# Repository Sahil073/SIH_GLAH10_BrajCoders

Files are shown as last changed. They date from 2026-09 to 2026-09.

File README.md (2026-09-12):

# Sanjeevni: Offline Wearable Telemetry & Edge AI Companion







Sanjeevni is an offline-first wearable telemetry system and on-device health safety companion. Designed for industrial workers, underground miners, high-altitude workers, and remote patients, it continuously captures physiological and environmental vitals via a multi-sensor ESP32 wearable and streams them over Bluetooth Low Energy (BLE) to an Android smartphone.

All biomedical signal processing, Pan-Tompkins QRS detection, motion classification, heat-stress modeling, and risk scoring execute locally on the mobile device CPU. No internet connection, cellular data, or external cloud infrastructure is required.

---

## System Architecture & Data Pipeline

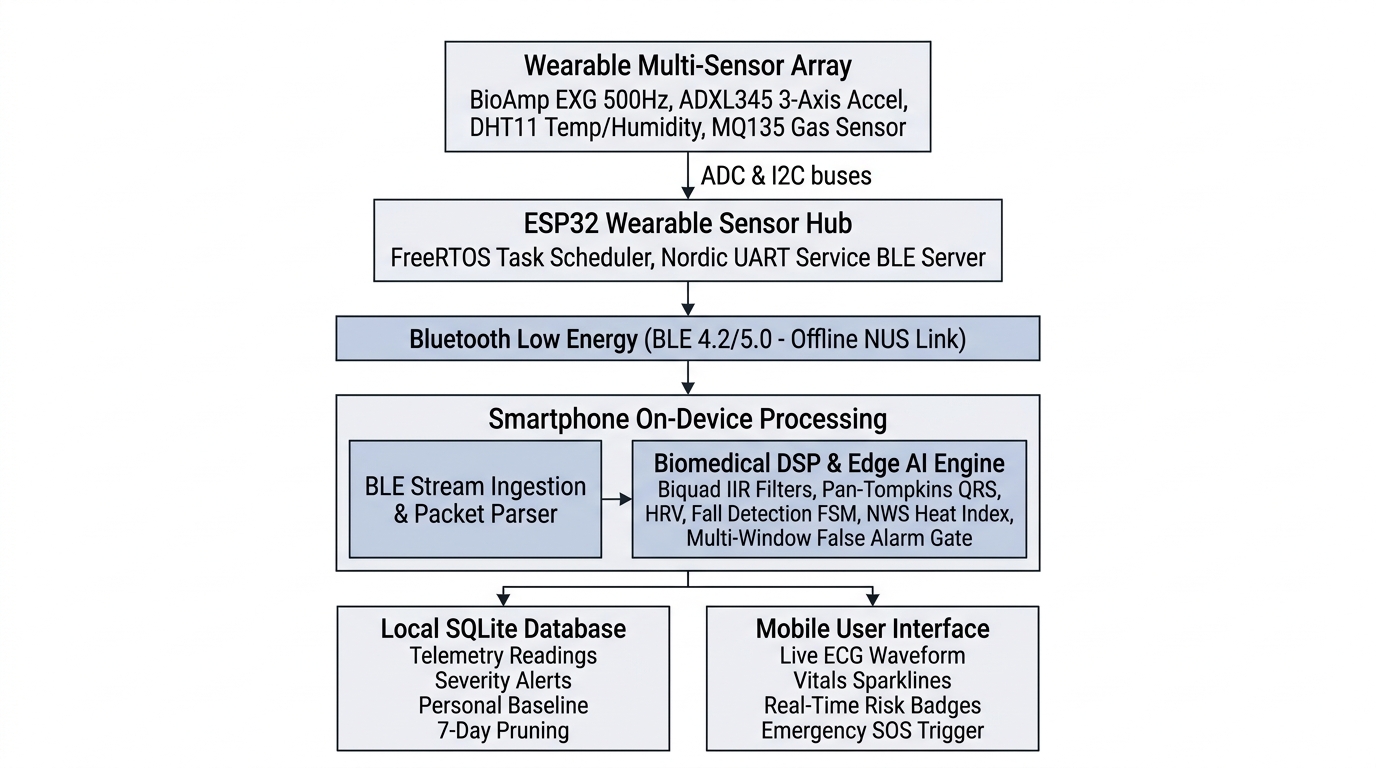
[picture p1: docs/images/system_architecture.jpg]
Sanjeevni System Architecture


---

## Repository Structure

```text
SIH_GLAH10_BrajCoders/
├── Hardware/                          # Firmware, testing sketches, PCB and hardware docs
│   ├── Device-Testing/                # 2-Tier component verification suite
│   │   ├── ADXL345/                   # Standalone I2C accelerometer serial test
│   │   ├── ADXL_Bluetooth/            # BLE stream test for ADXL345 (25 Hz)
│   │   ├── Bioamp_EXG/                # Standalone biopotential ADC serial test
│   │   ├── Bioamp_EXG_Bluetooth/      # BLE stream test for BioAmp EXG (500 Hz, 128-sample)
│   │   ├── Bluetooth/                 # BLE NUS loopback echo test
│   │   ├── DHT11/                     # Standalone digital temperature/humidity test
│   │   ├── DHT_Bluetooth/             # BLE stream test for DHT11 (0.5 Hz)
│   │   ├── LED/                       # GPIO and ESP32 clock sanity check
│   │   ├── MQ135/                     # Standalone hazardous gas ADC serial test
│   │   ├── MQ135_Bluetooth/           # BLE stream test for MQ135 (1 Hz)
│   │   ├── Moisture/                  # Standalone moisture ADC serial test
│   │   ├── Moisture_Bluetooth/        # BLE stream test for moisture sensor (0.5 Hz)
│   │   └── DEVICE_TESTING_GUIDE.md    # Modular hardware verification instructions
│   ├── ESP32_Sensor_Hub/              # Production multi-sensor BLE firmware
│   │   └── ESP32_Sensor_Hub.ino       # Full FreeRTOS multi-rate scheduler
│   ├── Sanjeevni_PCB/                 # Custom KiCad PCB files & manufacturing guide
│   │   ├── Sanjeevni_PCB.kicad_sch    # Schematic design
│   │   ├── Sanjeevni_PCB.kicad_pcb    # 2-layer PCB layout
│   │   ├── PCB schema.pdf             # Exported schematic reference
│   │   ├── PCB design.pdf             # Exported board layout reference
│   │   ├── PCB_Schematic.pdf          # Exported schematic reference
│   │   ├── PCB_Design.pdf             # Exported board layout reference
│   │   ├── PCB_Design_Guide.md        # Comprehensive electrical BOM and layout notes
│   │   ├── README.md                  # PCB subsystem overview and stackup
│   │   └── images/                    # 3D board renders
│   ├── HARDWARE_DOCS.md               # Pinouts, electrical specifications and BLE format
│   ├── README.md                      # Hardware overview and getting started guide
│   └── sample_data.txt                # 1,130 lines of verified field telemetry
│
├── docs/                              # Project specifications and hackathon decks
│   ├── images/                        # Research-style architecture and system diagrams
│   ├── BrajCoder's_SIH_Round1.pdf     # Smart India Hackathon Round 1 presentation
│   ├── BrajCoders_SIH_Round1.pdf      # Smart India Hackathon Round 1 presentation
│   ├── BrajCoders_SIH_2026.pdf        # SIH project submission & architectural slides
│   ├── sanjeevni_app_spec.pdf         # Mobile application technical specification
│   ├── sanjeevni_buildguide.pdf       # Hardware assembly and prototyping guide
│   └── DOCS_GUIDE.md                  # Index and overview of project documents
│
├── mobile-app/                        # React Native + Expo mobile application
│   ├── ai-engine/                     # On-device biomedical DSP and decision pipeline
│   │   ├── baseline/                  # Welford's online running baseline engine
│   │   ├── buffers/                   # High-performance RingBuffer
│   │   ├── decision/                  # Multi-window false-alarm gate & risk rules
│   │   ├── ecg/                       # Biquad IIR filters, Pan-Tompkins, HR & HRV
│   │   ├── environment/               # NWS Rothfusz heat index & AQI classifier
│   │   ├── fusion/                    # Multi-modal cross-sensor risk fusion
│   │   ├── mock/                      # Synthetic telemetry generator for simulator mode
│   │   ├── motion/                    # Dynamic activity state & 3-stage fall FSM
│   │   ├── __tests__/                 # Automated 7-test AI pipeline test suite
│   │   ├── index.ts                   # processSensorTick() main entrypoint
│   │   ├── types.ts                   # Strict data contracts for all sensor inputs
│   │   └── README.md                  # Comprehensive mathematical specification
│   ├── databaseConnections/           # On-device SQLite persistence layer
│   │   ├── database.ts                # Schema v4 table definitions, CRUD & pruning
│   │   ├── database.web.ts            # Web-safe mock fallback for browsers
│   │   ├── __tests__/                 # Automated 12-test database test suite
│   │   └── README.md                  # Table schemas, indices & retention policy
│   ├── src/                           # Mobile frontend source code
│   │   ├── app/                       # Expo Router tab layouts and navigation screens
│   │   │   ├── (auth)/                # Sign-in and sign-up flows (Clerk auth)
│   │   │   ├── (tabs)/                # Dashboard, Alerts, History, SOS, Profile
│   │   │   ├── _layout.tsx            # App initialization, providers & DB/AI bridge
│   │   │   └── connect-device.tsx     # BLE device discovery and pairing screen
│   │   ├── ble/                       # BLE Central manager, reassembly & reactive store
│   │   ├── components/                # Reusable UI widgets, sparklines, modals
│   │   ├── database/                  # On-device SQLite persistence layer (Schema v4)
│   │   │   ├── index.ts               # Public API wrapper & multi-user queries
│   │   │   ├── database.ts            # Schema definitions, CRUD & retention pruning
│   │   │   ├── database.web.ts        # Web-safe mock fallback for browsers
│   │   │   ├── vitalsHistory.ts       # Time-series vitals history query service
│   │   │   ├── __tests__/             # Automated 12-test database test suite
│   │   │   └── README.md              # Table schemas, indices & retention policy
│   │   ├── hooks/                     # Custom hooks (useDashboardData, useBle, useAiRisk)
│   │   └── services/                  # aiBridge.ts (BLE -> AI Pipeline -> SQLite)
│   ├── __tests__/                     # End-to-end hardware-to-UI integration test
│   ├── app.json                       # Expo configuration, Android permissions & plugins
│   ├── eas.json                       # Standalone APK build profile (arm64-v8a)
│   ├── package.json                   # Mobile dependencies and npm scripts
│   └── README.md                      # Mobile subsystem documentation
│
├── package.json                       # Root developer convenience test scripts
└── README.md                          # Project documentation and run guide
```

---

## Hardware Setup & Firmware Flashing

### 1. Prerequisites

- **Arduino IDE**: Version 2.x ([Download Arduino IDE](https://www.arduino.cc/en/software))
- **ESP32 Board Package**: Install `esp32` by Espressif via `Boards Manager`
- **Required Libraries** (via `Tools > Manage Libraries...`):
  - `Adafruit ADXL345`
  - `Adafruit Unified Sensor`
  - `DHT sensor library` (by Adafruit)
  - `ArduinoJson` (by Benoit Blanchon, v6.x or v7.x)

### 2. Sensor Pinout Mapping

| Sensor Module | Physical Interface | ESP32 GPIO | Operating Voltage | Notes |
| :--- | :--- | :--- | :--- | :--- |
| **BioAmp EXG Pill** | Analog Voltage | `GPIO 34` | 3.3V | ADC1_CH6 (Input-only, 500 Hz sampling) |
| **ADXL345** | I2C | `GPIO 21` (SDA)<br>`GPIO 22` (SCL) | 3.3V | I2C Address `0x53` (SDO to GND) |
| **DHT11** | Proprietary 1-Wire | `GPIO 4` | 3.3V / 5V | Digital I/O (10 kΩ pull-up required if bare) |
| **MQ135** | Analog Voltage | `GPIO 35` | 5.0V (Heater)<br>3.3V (ADC) | ADC1_CH7 (Input-only, heater requires 5V) |
| **Moisture Sensor** | Analog Voltage | `GPIO 32` | 3.3V | ADC1_CH4 (Supports digital and analog) |

> **Critical ADC Note:** Only ADC1 pins are used. ADC2 pins (`GPIO 0, 2, 4, 12, 13, 14, 15, 25, 26, 27`) cannot be used for analog reads when Bluetooth or Wi-Fi is active.

### 3. Flashing the Sensor Hub Firmware

1. Connect your ESP32 Dev Module via micro-USB.
2. In Arduino IDE, select:
   - **Board**: `ESP32 Dev Module`
   - **Upload Speed**: `921600`
   - **Flash Frequency**: `80MHz`
   - **Port**: Select your active COM port.
3. Open [`Hardware/ESP32_Sensor_Hub/ESP32_Sensor_Hub.ino`](Hardware/ESP32_Sensor_Hub/ESP32_Sensor_Hub.ino).
4. Click **Upload**.
5. Once uploaded, open the Serial Monitor at `115200 baud`. The ESP32 will initialize all sensors and start advertising over BLE as **`ESP32_SENSOR_HUB_BLE`**.

---

## Mobile App Setup & Execution

### 1. Prerequisites

- **Node.js**: v18.x or v20.x LTS ([Download Node.js](https://nodejs.org))
- **npm**: v9.x or higher
- **Physical Android Phone**: Bluetooth 4.2+ and Location enabled (for native BLE testing).

### 2. Installation & Configuration

```bash
# 1. Navigate to the mobile app directory
cd mobile-app

# 2. Copy the sample environment file
cp .env.example .env

# 3. Install dependencies
npm install --legacy-peer-deps
```

### 3. Running in Development

#### Option A: Expo Go (Simulation Mode)

```bash
npm start
```

- Scan the displayed QR code with the **Expo Go** application on Android.
- Because native BLE binary drivers are unavailable inside Expo Go, Sanjeevni automatically engages its built-in mathematical synthetic generator (`syntheticDataGenerator.ts`). It generates realistic 500 Hz ECG waveforms, accelerometer tilts, and ambient thermal cycles for full UI testing.

#### Option B: Standalone Android APK (Physical BLE Mode)

To connect to the physical ESP32 hardware, compile an installable standalone `.apk`:

```bash
# Via EAS Cloud Build:
npm install -g eas-cli
npx eas login
npx eas build -p android --profile preview

# Or compile locally with Gradle:
npx expo prebuild --platform android
cd android
./gradlew assembleRelease -PreactNativeArchitectures=arm64-v8a
```

Install the resulting `.apk` on your phone, enable Bluetooth, power on the ESP32, and launch Sanjeevni. The app will pair and start streaming telemetry without internet or Wi-Fi.

---

## Automated Verification & Test Suites

The project includes unit and integration tests across the entire stack. Run them from the workspace root:

### Run All Test Suites:

```bash
npm test
```

### Run Individual Test Suites:

1. **On-Device AI Engine Test Suite** (`7/7 Passed`):

   ```bash
   npm run test:ai
   ```

   - Test 1: Biquad IIR Bandpass (0.5–40 Hz) & 50 Hz Notch filter attenuation.
   - Test 2: Pan-Tompkins QRS peak detection and RR interval validation.
   - Test 3: Mathematical derivation of BPM, RMSSD, and SDNN.
   - Test 4: Dynamic motion classification and 3-stage fall detection FSM.
   - Test 5: Environmental Heat Index calculation against NOAA benchmark tables.
   - Test 6: Full end-to-end `processSensorTick()` pipeline orchestration.
   - Test 7: Multi-window emergency alarm and false-alarm gate trigger logic.

2. **SQLite Database & Schema Test Suite** (`12/12 Passed`):

   ```bash
   npm run test:db
   ```

   - Test 1: Schema creation, tables (`readings`, `alerts`, `user_profile`, `rolling_baseline`), and indices.
   - Test 2: Readings insertion and query operations.
   - Test 3: Alerts table insertion and severity enum check constraint (`LOW`, `MODERATE`, `HIGH`, `CRITICAL`).
   - Test 4: Single-profile configuration constraint.
   - Test 5: Rolling baseline upsert via `ON CONFLICT DO UPDATE`.
   - Test 6: Automated 7-day circular data pruning.
   - Test 7: Sensor aggregate statistics calculations.
   - Test 8: Historical sensor queries with timestamp ordering and pagination limits.
   - Test 9: Alert deletion and bulk clear operations.
   - Test 10: Rich user profile persistence and local session management.
   - Test 11: Multi-user data isolation and tenant partitioning.
   - Test 12: 6-month historical data rollup downsampling and user erasure utility.

3. **End-to-End System Integration Test**:

   ```bash
   npm run test:e2e
   ```

   - Step 1: Parses raw multi-chunk ESP32 Nordic UART BLE packets.
   - Step 2: Executes the sliding-window AI pipeline.
   - Step 3: Verifies persistent storage in the local SQLite database.

4. **TypeScript Type Checking**:
   ```bash
   npm run typecheck
   ```

   - Validates TypeScript types across the entire mobile codebase (0 errors).

---

## BLE Protocol Reference (Nordic UART Service)

The ESP32 communicates using the Nordic UART Service (NUS):

| Identifier | UUID Value |
| :--- | :--- |
| **Service UUID** | `6E400001-B5A3-F393-E0A9-E50E24DCCA9E` |
| **RX Characteristic (Write)**  | `6E400002-B5A3-F393-E0A9-E50E24DCCA9E` |
| **TX Characteristic (Notify)** | `6E400003-B5A3-F393-E0A9-E50E24DCCA9E` |

### Telemetry Packet Payloads (Newline Delimited `\n`)

- **BioAmp EXG (Sensor ID 1)**:
  `{"v":1,"sensor":1,"seq":104,"rate":500,"samples":[2048,2060,2090,...],"ts":181482}\n`
- **ADXL345 (Sensor ID 2)**:
  `{"v":1,"sensor":2,"seq":4518,"data":{"x":0.15,"y":-0.22,"z":9.81},"ts":181483}\n`
- **DHT11 (Sensor ID 3)**:
  `{"v":1,"sensor":3,"seq":120,"data":{"temperature":32.5,"humidity":68.0},"ts":181500}\n`
- **MQ135 (Sensor ID 4)**:
  `{"v":1,"sensor":4,"seq":180,"data":{"raw":480},"ts":181751}\n`
- **Moisture Sensor (Sensor ID 5)**:
  `{"v":1,"sensor":5,"seq":95,"data":{"raw":520},"ts":181800}\n`

---

## Offline Privacy & Data Integrity

- **Zero Cloud Transmission**: All ECG analysis, Pan-Tompkins QRS detection, and environmental evaluations execute on the smartphone CPU. No biometric data leaves the device.
- **Local SQLite Retention**: Telemetry and safety alerts are stored in an encrypted/sandboxed local SQLite database (`sanjeevni.db`) with an automated 7-day circular pruning policy to preserve phone storage.
- **Credential Protection**: Environment files and keys are excluded via `.gitignore`.

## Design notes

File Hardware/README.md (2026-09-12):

# Hardware Subsystem — ESP32 Sensor Hub

This directory contains the firmware, modular hardware testing suite, KiCad custom PCB designs, and hardware documentation for the Sanjeevni wearable device.

---

## Directory Structure

```text
Hardware/
├── ESP32_Sensor_Hub/              # Production multi-sensor BLE GATT firmware
│   └── ESP32_Sensor_Hub.ino       # Non-blocking multi-rate scheduler and NUS streamer
├── Device-Testing/                # Modular 2-tier testing sketches & verification guide
│   ├── ADXL345/                   # Standalone I2C accelerometer diagnostic
│   ├── ADXL_Bluetooth/            # Component-level BLE test for ADXL345 (25 Hz)
│   ├── Bioamp_EXG/                # Standalone biopotential ADC diagnostic (Serial Plotter)
│   ├── Bioamp_EXG_Bluetooth/      # Component-level BLE test for BioAmp EXG (500 Hz, 128-sample chunks)
│   ├── Bluetooth/                 # BLE NUS bidirectional loopback and throughput test
│   ├── DHT11/                     # Standalone digital temperature and humidity diagnostic
│   ├── DHT_Bluetooth/             # Component-level BLE test for DHT11 (0.5 Hz)
│   ├── LED/                       # GPIO driver and ESP32 clock sanity check
│   ├── MQ135/                     # Standalone hazardous gas ADC diagnostic
│   ├── MQ135_Bluetooth/           # Component-level BLE test for MQ135 (1 Hz)
│   ├── Moisture/                  # Standalone skin/soil moisture ADC diagnostic
│   ├── Moisture_Bluetooth/        # Component-level BLE test for moisture sensor (0.5 Hz)
│   └── DEVICE_TESTING_GUIDE.md    # Complete test procedure and output reference
├── Sanjeevni_PCB/                 # Custom hardware PCB design files
│   ├── Sanjeevni_PCB.kicad_sch    # KiCad schematic
│   ├── Sanjeevni_PCB.kicad_pcb    # KiCad 2-layer PCB layout
│   ├── PCB schema.pdf             # Exported schematic PDF
│   ├── PCB design.pdf             # Exported board layout PDF
│   ├── PCB_Schematic.pdf          # Exported schematic PDF
│   ├── PCB_Design.pdf             # Exported board layout PDF
│   ├── PCB_Design_Guide.md        # Circuit theory, BOM, and assembly guide
│   ├── README.md                  # PCB folder overview and layer stackup
│   └── images/                    # 3D renders (top view, isometric views)
├── HARDWARE_DOCS.md               # Detailed hardware specification and electrical reference
└── sample_data.txt                # 1,130 lines of live captured telemetry from field testing
```

---

## Sensor Interface & Pin Allocations

These pin allocations are strictly adhered to by the production firmware [`ESP32_Sensor_Hub.ino`](ESP32_Sensor_Hub/ESP32_Sensor_Hub.ino) and all Tier 2 BLE testing sketches:

| Sensor Module | Physical Interface | ESP32 GPIO | Channel / Type | Sampling Rate | BLE Transmission Rate |
| :--- | :--- | :--- | :--- | :--- | :--- |
| **BioAmp EXG Pill** | Analog Voltage Out | `GPIO 34` | ADC1_CH6 (Input-only) | 500 Hz (2 ms period via `micros()`) | ~3.9 Hz (128 samples / packet) |
| **ADXL345** | I2C (Address `0x53`) | `GPIO 21` (SDA)<br>`GPIO 22` (SCL) | Hardware I2C | 100 Hz (10 ms period) | 25 Hz (40 ms period) |
| **DHT11** | Proprietary 1-Wire | `GPIO 4` | Digital I/O | 0.5 Hz (2000 ms period) | 0.5 Hz |
| **MQ135** | Analog Voltage Out | `GPIO 35` | ADC1_CH7 (Input-only) | 10 Hz (100 ms period) | 1 Hz (10-sample rolling average) |
| **Moisture Sensor** | Analog Voltage Out | `GPIO 32` | ADC1_CH4 (ADC + Digital) | 10 Hz (100 ms period) | 0.5 Hz (10-sample rolling average) |

> **ADC Note:** All analog sensors use ADC1 pins (`GPIO 32`, `34`, `35`). In ESP32 microcontrollers, ADC2 cannot be used simultaneously with active Wi-Fi or Bluetooth Low Energy due to internal RF hardware multiplexing.

---

## Bluetooth Low Energy Protocol (NUS)

The ESP32 firmware operates as a BLE GATT Server running the **Nordic UART Service (NUS)**:

- **Advertised Peripheral Name:** `ESP32_SENSOR_HUB_BLE`
- **Primary Service UUID:** `6E400001-B5A3-F393-E0A9-E50E24DCCA9E`
- **TX Characteristic (Notify):** `6E400003-B5A3-F393-E0A9-E50E24DCCA9E` (Descriptor: `0x2902`)
- **RX Characteristic (Write):** `6E400002-B5A3-F393-E0A9-E50E24DCCA9E`
- **Negotiated MTU:** 517 bytes (`BLEDevice::setMTU(517)`)
- **Chunking:** Payloads are split into max 128-byte notifications with 2 ms yields to prevent notify buffer congestion.
- **Framing:** Compact JSON terminated by `\n` (newline).

### Packet Format Overview

Every packet includes version `"v": 1`, a numeric `"sensor"` ID (1–5), an independent per-sensor sequence number `"seq"`, and uptime `"ts"` in milliseconds:

```json
// Sensor 1: BioAmp EXG (500 Hz batch)
{"v":1,"sensor":1,"seq":104,"ts":181482,"rate":500,"samples":[2048,2060,2090,2085,...]}

// Sensor 2: ADXL345 Accelerometer (m/s²)
{"v":1,"sensor":2,"seq":4518,"ts":181483,"data":{"x":0.15,"y":-0.22,"z":9.81}}

// Sensor 3: DHT11 Temperature & Humidity
{"v":1,"sensor":3,"seq":120,"ts":181500,"data":{"temperature":32.5,"humidity":68.0}}

// Sensor 4: MQ135 Air Quality (raw 12-bit ADC)
{"v":1,"sensor":4,"seq":180,"ts":181751,"data":{"raw":480}}

// Sensor 5: Moisture (raw 12-bit ADC)
{"v":1,"sensor":5,"seq":95,"ts":181800,"data":{"raw":520}}
```

---

## Flashing Instructions

### Required Environment
- **Arduino IDE**: Version 2.0 or higher
- **Board Package**: `esp32` by Espressif Systems (v2.0.x or v3.0.x)
- **Board Selection**: `Tools > Board > esp32 > ESP32 Dev Module`
- **Upload Settings**:
  - Upload Speed: `921600`
  - CPU Frequency: `240MHz`
  - Flash Frequency: `80MHz`
  - Flash Mode: `QIO`
  - Partition Scheme: `Default 4MB with spiffs (1.2MB APP/1.5MB SPIFFS)`

### Required Arduino Libraries
Install these via the Arduino Library Manager (`Ctrl+Shift+I` / `Cmd+Shift+I`):
1. `Adafruit ADXL345` (Unified accelerometer driver)
2. `Adafruit Unified Sensor` (Base sensor abstraction)
3. `DHT sensor library` by Adafruit
4. `ArduinoJson` by Benoit Blanchon (version 6.x or 7.x)

The BLE stack (`BLEDevice`, `BLEServer`, `BLEUtils`, `BLE2902`) and `Wire` are included in the ESP32 core.

---

## Verification Workflow

1. **Standalone Validation**:
   Follow [`Device-Testing/DEVICE_TESTING_GUIDE.md`](Device-Testing/DEVICE_TESTING_GUIDE.md) to flash the standalone sketches (`ADXL345.ino`, `Bioamp_EXG.ino`, `DHT11.ino`, `MQ135.ino`, `Moisture.ino`) and view live physical metrics on the Serial Plotter (115200 baud).
2. **BLE Validation**:
   Flash the corresponding `*_Bluetooth.ino` sketches to verify BLE GATT discovery, characteristic subscriptions, and packet throughput.
3. **Full Integration**:
   Flash [`ESP32_Sensor_Hub/ESP32_Sensor_Hub.ino`](ESP32_Sensor_Hub/ESP32_Sensor_Hub.ino). Verify serial output confirms all sensors initialized, then connect using the Sanjeevni mobile application.
4. **Captured Telemetry**:
   Review [`sample_data.txt`](sample_data.txt) for real-world serial logs and payload samples recorded during field testing.

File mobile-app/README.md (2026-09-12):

# Sanjeevni Mobile Application

The Sanjeevni mobile application is an offline-first wearable telemetry and on-device health companion built with React Native and Expo (SDK 57). It connects to the ESP32 Wearable Sensor Hub over Bluetooth Low Energy (BLE) using the Nordic UART Service (NUS) to perform continuous biopotential signal processing, environmental safety analysis, motion tracking, and automated emergency alerting without requiring internet, cellular data, or cloud servers.

---

## Architecture Overview

The mobile application is structured into four decoupled layers:

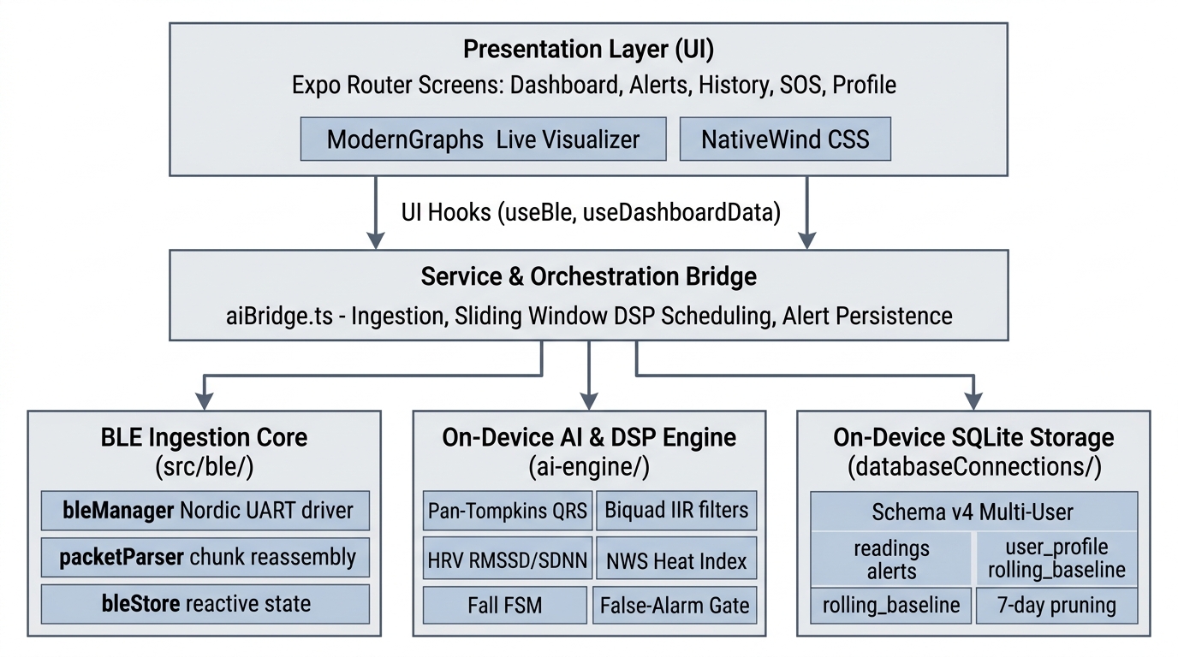
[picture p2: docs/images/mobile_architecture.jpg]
Sanjeevni Mobile Architecture


---

## Directory Structure

```text
mobile-app/
├── ai-engine/                          # Zero-dependency biomedical DSP & risk engine
│   ├── baseline/                       # Welford's running baseline & cold-start logic
│   ├── buffers/                        # Ring buffer for sliding-window calculations
│   ├── decision/                       # False-alarm hysteresis & risk decision engine
│   ├── ecg/                            # Biquad IIR filters, Pan-Tompkins, HR & HRV
│   ├── environment/                    # NWS Rothfusz heat index & AQI classifier
│   ├── fusion/                         # Multi-modal cross-sensor risk fusion
│   ├── mock/                           # Synthetic wave generator for simulator mode
│   ├── motion/                         # Activity state & fall detection state machine
│   ├── __tests__/                      # 7-test AI pipeline verification suite
│   ├── index.ts                        # processSensorTick() orchestrator
│   ├── package.json                    # Isolated package definition
│   └── README.md                       # In-depth DSP mathematical specification
├── databaseConnections/                # Local SQLite persistence engine
│   ├── database.ts                     # Schema v4 table definitions, CRUD & pruning
│   ├── database.web.ts                 # Safe in-memory mock fallback for web
│   ├── __tests__/                      # 12-test SQLite schema verification suite
│   └── README.md                       # Table schemas, indices & retention policy
├── src/                                # Mobile application source code
│   ├── app/                            # Expo Router file-based navigation
│   │   ├── (auth)/                     # Sign-in and sign-up views (Clerk auth)
│   │   ├── (tabs)/                     # Main bottom-tab views:
│   │   │   ├── index.tsx               # Dashboard (Live ECG, vitals sparklines, status)
│   │   │   ├── alerts.tsx              # Safety alerts log with acknowledgment
│   │   │   ├── history.tsx             # Historical telemetry trends & export
│   │   │   ├── sos.tsx                 # Emergency SOS trigger & contact calling
│   │   │   └── profile.tsx             # Medical profile, blood group & baselines
│   │   ├── _layout.tsx                 # Root layout, theme provider, DB initialization
│   │   ├── connect-device.tsx          # BLE device discovery & pairing modal
│   │   ├── onboarding.tsx              # First-launch feature walkthrough
│   │   └── onboarding-health.tsx       # Initial medical baseline setup
│   ├── ble/                            # Self-contained Bluetooth Low Energy module
│   │   ├── bleManager.ts               # Nordic UART Service GATT driver & auto-reconnect
│   │   ├── packetParser.ts             # Stream reassembly buffer & Base64/JSON parser
│   │   ├── bleStore.ts                 # Reactive telemetry store
│   │   ├── types.ts                    # Sensor contracts (Sensors 1-5)
│   │   ├── hooks/useBleConnection.ts   # Presentational hook for UI connection screens
│   │   └── README.md                   # BLE integration documentation
│   ├── components/                     # Modular UI components (charts, cards, banners)
│   ├── constants/                      # Image registries and theme constants
│   ├── data/                           # Mock datasets and metric details
│   ├── database/                       # Local SQLite persistence engine
│   │   ├── index.ts                    # Public API wrapper & safe multi-user queries
│   │   ├── database.ts                 # Schema v4 table definitions, CRUD & pruning
│   │   ├── database.web.ts             # Safe in-memory mock fallback for web
│   │   ├── vitalsHistory.ts            # Time-series vitals history aggregation service
│   │   ├── __tests__/                  # 12-test SQLite schema verification suite
│   │   └── README.md                   # Table schemas, indices & retention policy
│   ├── hooks/                          # Custom React hooks (useDashboardData, etc.)
│   ├── services/                       # aiBridge.ts (BLE -> AI Engine -> SQLite)
│   ├── store/                          # User profile and UI state stores
│   └── types/                          # Shared UI and dashboard types
├── __tests__/                          # Full end-to-end integration test
├── assets/                             # Fonts (Poppins) and app icons
├── plugins/                            # Custom Expo config plugins (ABI optimizations)
├── app.json                            # Expo manifest, Android permissions & plugins
├── eas.json                            # EAS build configuration (arm64-v8a target)
├── package.json                        # Mobile dependencies and npm scripts
├── tailwind.config.js                  # NativeWind Tailwind configuration
└── tsconfig.json                       # TypeScript compiler configuration with @/* aliases
```

---

## Execution Modes

The app supports two execution modes depending on runtime environment:

### 1. Expo Go (Simulation Mode)
- **Use Case**: Fast UI and application state development without needing a physical ESP32.
- **Behavior**: Because native C++/JNI Bluetooth drivers (`react-native-ble-plx`) cannot run inside the pre-compiled Expo Go client, the application automatically engages `syntheticDataGenerator.ts`.
- **Telemetry**: Generates mathematically realistic ECG waveforms (P-Q-R-S-T complexes at 500 Hz), dynamic 3-axis accelerometer tilts, and fluctuating ambient temperature/humidity cycles.

### 2. Standalone APK / Development Build (Hardware Mode)
- **Use Case**: Testing with the physical ESP32 Wearable Sensor Hub.
- **Behavior**: Initializes the full native Android BLE Central stack, requests necessary runtime permissions (`BLUETOOTH_SCAN`, `BLUETOOTH_CONNECT`, `ACCESS_FINE_LOCATION`), discovers `ESP32_SENSOR_HUB_BLE`, negotiates MTU 517, and ingests live sensor packets.

---

## Getting Started

### Prerequisites
- **Node.js**: v18.x or v20.x LTS
- **npm**: v9.x or higher
- **Expo CLI**: bundled via `npx expo`

### 1. Installation
Navigate to the `mobile-app` directory and install dependencies:
```bash
cd mobile-app
npm install --legacy-peer-deps
```

### 2. Environment Configuration
Copy the sample environment file:
```bash
cp .env.example .env
```
Edit `.env` if you need to configure authentication keys (a default offline bypass key is pre-filled).

### 3. Run in Development
Start the Expo bundler:
```bash
npm start
```
- Press **`a`** to open in an Android emulator.
- Scan the terminal QR code with **Expo Go** on an Android phone to run in Simulation Mode.

---

## Compiling Standalone Android APK

Because physical BLE communication requires native Android binaries, compile a standalone `.apk` for hardware testing:

### Option A: Cloud Build via EAS (Recommended)
```bash
# 1. Install EAS CLI
npm install -g eas-cli

# 2. Login to Expo
npx eas login

# 3. Build standalone preview APK
npx eas build -p android --profile preview
```

> **Build Optimization:** `eas.json` and `plugins/withReactNativeArchitectures.js` are configured to compile exclusively for `arm64-v8a`. This avoids building redundant 32-bit and emulator ABIs, reducing cloud compile times to ~6–8 minutes.

### Option B: Local Android Build
```bash
# 1. Generate native android project
npx expo prebuild --platform android

# 2. Compile release APK with Gradle
cd android
./gradlew assembleRelease -PreactNativeArchitectures=arm64-v8a
```
Output APK is located at: `android/app/build/outputs/apk/release/app-release.apk`.

---

## Testing & Verification

All test suites can be executed directly:

```bash
# 1. AI Biomedical DSP Test (7 tests):
npx tsx ai-engine/__tests__/aiPipeline.test.ts

# 2. SQLite Database & Schema Test (12 tests):
npx tsx databaseConnections/__tests__/databaseSchema.test.ts
npx tsx src/database/__tests__/databaseSchema.test.ts

# 3. Full End-to-End System Integration Test:
npx tsx __tests__/endToEndIntegration.test.ts

# 4. TypeScript Typecheck:
npm run typecheck
```

Or execute all tests in sequence:
```bash
npm test
```

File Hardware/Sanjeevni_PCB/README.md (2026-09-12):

# Sanjeevni Custom Wearable PCB

This directory contains the schematic design, printed circuit board (PCB) layout, 3D renderings, and manufacturing guidelines for the Sanjeevni wearable hardware prototype, designed using KiCad.

---

## Directory Contents

| File / Folder | Type | Description |
| :--- | :--- | :--- |
| [`Sanjeevni_PCB.kicad_sch`](Sanjeevni_PCB.kicad_sch) | KiCad Schematic | Full schematic capture including power regulation, ESP32 core, sensor front-ends, and programming pads. |
| [`Sanjeevni_PCB.kicad_pcb`](Sanjeevni_PCB.kicad_pcb) | KiCad Board Layout | 2-layer PCB layout routing power planes, high-frequency digital lines, and shielded analog tracks. |
| [`Sanjeevni_PCB.kicad_pro`](Sanjeevni_PCB.kicad_pro) | Project File | KiCad project configuration and library mappings. |
| [`PCB schema.pdf`](<PCB schema.pdf>) | Schematic Export | High-resolution PDF export of the complete circuit schematic for easy review without KiCad installed. |
| [`PCB design.pdf`](<PCB design.pdf>) | Layout Export | High-resolution PDF export of the top and bottom copper layers, silkscreen, and drill guides. |
| [`PCB_Schematic.pdf`](PCB_Schematic.pdf) | Schematic Export | High-resolution PDF export of the complete circuit schematic for easy review without KiCad installed. |
| [`PCB_Design.pdf`](PCB_Design.pdf) | Layout Export | High-resolution PDF export of the top and bottom copper layers, silkscreen, and drill guides. |
| [`PCB_Design_Guide.md`](PCB_Design_Guide.md) | Engineering Guide | In-depth documentation detailing the Bill of Materials (BOM), trace width calculations, noise isolation, and step-by-step routing methodology. |
| [`images/`](images/) | 3D Visualizations | Rendered views of the populated board: [top view](images/top%20view.png), [isometric view 1](images/isometric%20view.png), [isometric view 2](images/isometric%20view%202.png). |
| [`images/`](images/) | 3D Visualizations | Rendered views of the populated board: [top view](images/top_view.png), [isometric view 1](images/isometric_view_1.png), [isometric view 2](images/isometric_view_2.png). |

---

## Hardware Architecture & Design Decisions

### 1. Form Factor & Enclosure Considerations
- **Field-Sealed Wearable**: To ensure durability in harsh industrial or remote environments, the production board does not include an onboard micro-USB or Type-C port. 
- **Factory Programming Interface**: 6 exposed test pads (`GND`, `3V3`, `TX`, `RX`, `EN`, `IO0`) are positioned along the board edge, allowing firmware programming via a removable pogo-pin jig before sealing.
- **Power Connection**: 2-pin JST-PH 2.00 mm horizontal receptacle for standard 3.7V single-cell LiPo rechargeable batteries.

### 2. Sensor Integration Strategy
- **BioAmp EXG Pill (Daughterboard)**: Mounted via standard 2.54 mm female pin headers rather than integrating bare IC components. This isolates the sensitive biopotential instrumentation amplifier (110 dB CMRR, 4th-order active bandpass filter) from digital switching noise and RF ground bounce.
- **ADXL345 (Bare IC)**: Direct LGA-14 surface mount footprint on the I2C bus (`GPIO 21` SDA, `GPIO 22` SCL) with 4.7 kΩ pull-up resistors and local 100 nF decoupling.
- **DHT11 (Through-Hole Footprint)**: 4-pin single-row connector with pull-up resistor on the single-wire data line (`GPIO 4`).
- **MQ135 (Raw Element)**: 6-pin circular footprint for the bare electrochemical gas sensing element. Driven by an onboard MT3608 boost converter providing the required 5V rail for the internal heating element.

### 3. Power Distribution Architecture
- **Battery Input**: 3.7V nominal LiPo (operating range 3.0V – 4.2V).
- **3.3V Logic Rail**: AMS1117-3.3 low-dropout linear regulator providing clean 3.3V power to the ESP32-WROOM-32D module, ADXL345, DHT11, and BioAmp EXG Pill. Bulk decoupling capacitors (10 µF tantalum + 100 nF ceramic) are placed directly at the regulator and MCU pins.
- **5.0V Heater Rail**: MT3608 DC-DC step-up switching regulator stepping 3.7V up to 5.0V dedicated exclusively to the MQ135 heating coil. Thermal relief vias and a dedicated ground return keep switching noise out of the analog measurement circuits.

---

## Fabrication Specifications

- **Layer Count**: 2 Layers (Top Layer: Signal & Power, Bottom Layer: Unbroken Ground Plane)
- **Board Material**: Standard FR-4
- **Finished Copper Weight**: 1 oz (35 µm)
- **Dielectric Thickness**: 1.6 mm
- **Minimum Trace Width**: 0.25 mm (10 mil) for signal traces; 0.6 mm (24 mil) for 3.3V power distribution
- **Minimum Clearance**: 0.2 mm (8 mil)
- **Minimum Drill Hole Size**: 0.3 mm (via), 0.9 mm (through-hole component pins)

For the complete component catalog, KiCad symbol mappings, and step-by-step routing layout instructions, consult [`PCB_Design_Guide.md`](PCB_Design_Guide.md).

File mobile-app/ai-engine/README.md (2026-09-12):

# On-Device AI & Biomedical DSP Engine

This directory contains the core digital signal processing (DSP), statistical feature extraction, sensor fusion, and risk decision engine for Sanjeevni. It is designed as an isolated, zero-dependency TypeScript module that executes entirely on the mobile CPU (100% offline).

---

## Architectural Principles

1. **Deterministic DSP & Statistical Rules (Phase 1)**:
   Avoids heavyweight black-box neural networks in favour of validated biomedical algorithms (Pan-Tompkins QRS detection, Biquad IIR filtering, Welford's online variance, NWS Rothfusz polynomial). This guarantees real-time execution (<5 ms per tick) with minimal battery consumption and predictable failure modes.
2. **Zero Framework Coupling**:
   No dependencies on React Native, Expo, or native OS binaries. The engine can be tested directly in Node.js or run inside a Web Worker, headless service, or mobile JavaScript runtime.
3. **Strict Per-User State Isolation**:
   Filter memories, ring buffers, and baseline tracking are maintained in per-user instances (`runtimeByUser = Map<string, RuntimeState>()`) to eliminate cross-session data contamination.
4. **Physiologically Conservative**:
   Missing or noise-corrupted sensor inputs remain explicitly `null` rather than falling back to default "healthy" constants.

---

## Subsystem Breakdown

```text
ai-engine/
├── baseline/                  # Welford's running baseline & cold-start calibration
│   └── personalBaseline.ts
├── buffers/                   # High-performance sliding-window buffers
│   └── ringBuffer.ts          # O(1) circular ring buffer implementation
├── decision/                  # Alarm confirmation & recommendation generation
│   ├── falseAlarmGate.ts      # Multi-window persistence & motion masking
│   └── riskDecisionEngine.ts  # Final risk stratification and SOS trigger logic
├── ecg/                       # Biomedical signal processing pipeline
│   ├── filters.ts             # Biquad IIR 0.5–40 Hz bandpass + 50 Hz notch filter
│   ├── sqi.ts                 # Motion-aware Signal Quality Index (kurtosis, SNR)
│   ├── rPeakDetection.ts      # Pan-Tompkins adaptive dual-threshold peak detector
│   ├── rrValidation.ts        # 300–2000 ms physiological interval validation
│   ├── heartRate.ts           # Rolling heart rate (BPM) calculation
│   ├── hrv.ts                 # Time-domain HRV extraction (RMSSD, SDNN)
│   └── rhythmAnomaly.ts       # Bradycardia, tachycardia & arrhythmia detection
├── environment/               # Microclimate & environmental hazard modeling
│   ├── aqiSource.ts           # MQ135 ADC mapping to EPA AQI bands
│   ├── heatIndex.ts           # NWS Rothfusz equation & Steadman regression
│   └── respiratoryRisk.ts     # Combined thermal-gas pulmonary hazard scoring
├── fusion/                    # Multi-modal risk aggregation
│   └── sensorFusion.ts        # Weighted cross-domain risk synthesis
├── mock/                      # Hardware simulation for Expo Go
│   └── syntheticDataGenerator.ts # Generates realistic P-Q-R-S-T waves & tilt
├── __tests__/                 # Automated test suite
│   └── aiPipeline.test.ts     # 7-stage pipeline verification
├── types.ts                   # Strict data contracts for all inputs & outputs
├── index.ts                   # Public orchestrator: processSensorTick()
└── package.json               # Standalone package definition
```

---

## Algorithm Details

### 1. ECG Signal Conditioning (`ecg/filters.ts`)
Raw 500 Hz analog samples from the BioAmp EXG Pill undergo a 2-stage digital filtering cascade:
- **0.5–40 Hz Bandpass Filter**: Second-order IIR Biquad filters suppress baseline wander caused by respiration (<0.5 Hz) and electromyographic muscle noise (>40 Hz).
- **50 Hz Notch Filter**: Second-order IIR Notch filter ($Q = 30$) eliminates AC mains hum from nearby electrical wiring.

### 2. Pan-Tompkins QRS Detection (`ecg/rPeakDetection.ts`)
The filtered biopotential stream is evaluated via a classical Pan-Tompkins implementation:
1. **Derivative Operator**: Emphasizes the steep slope of the QRS complex ($y[n] = (2x[n] + x[n-1] - x[n-3] - 2x[n-4]) / 8$).
2. **Squaring Function**: Non-linearly amplifies the high-frequency QRS energy and forces all values positive.
3. **Moving Window Integrator**: Integrates energy over a 150 ms window ($\approx 75$ samples at 500 Hz).
4. **Adaptive Dual Thresholding**: Automatically adapts signal and noise peak thresholds based on running averages:
   $$\text{Threshold} = \text{NoiseLevel} + 0.25 \times (\text{SignalLevel} - \text{NoiseLevel})$$
5. **Refractory Blanking**: Enforces a 200 ms minimum lockout period between adjacent peaks to prevent double-counting T-waves.

### 3. Signal Quality Index (`ecg/sqi.ts`)
Before computing heart metrics, each batch of ECG samples is evaluated against three quality criteria:
- **Saturation / Lead-Off Check**: Flags ADC values locked at rails (`4095` or `0`).
- **Kurtosis & Relative Energy**: Computes 4th-order statistical moment to ensure peakiness characteristic of genuine QRS complexes.
- **Motion Gating**: Reads simultaneous dynamic acceleration from the ADXL345; if motion exceeds threshold, classifies as `MOTION_CORRUPTED` to prevent false arrhythmia triggers.

### 4. Heart Rate & HRV Calculation (`ecg/heartRate.ts`, `ecg/hrv.ts`)
- **RR Interval Validation**: Discards intervals outside 300 ms (200 BPM) to 2000 ms (30 BPM) or exhibiting unphysiological step jumps (>30% variance from previous interval).
- **Heart Rate**: Derived from the median of validated RR intervals over the observation window:
  $$\text{HR} = \frac{60000}{\text{median}(RR_i)} \text{ BPM}$$
- **RMSSD**: Root mean square of successive RR interval differences, reflecting parasympathetic autonomic activity:
  $$\text{RMSSD} = \sqrt{\frac{1}{N-1} \sum_{i=1}^{N-1} (RR_{i+1} - RR_i)^2}$$
- **SDNN**: Standard deviation of all normal-to-normal intervals over the observation window.

### 5. Fall Detection Finite State Machine (`motion/fallDetection.ts`)
Evaluates 3-axis accelerometer vectors $|\vec{a}| = \sqrt{x^2 + y^2 + z^2}$:
1. **Stage 1 (Freefall)**: Total vector drops below $0.5\text{g}$ for $\ge 60\text{ ms}$.
2. **Stage 2 (Impact)**: Vector experiences an abrupt acceleration spike exceeding $2.5\text{g}$ within $500\text{ ms}$ of freefall.
3. **Stage 3 (Post-Impact Immobility)**: Evaluates subsequent motion for $2.0\text{ s}$. If acceleration variance remains $<0.15\text{g}$, flags a `CONFIRMED` fall event.

### 6. Environmental Thermal Index (`environment/heatIndex.ts`)
Uses the comprehensive National Weather Service (NWS) Rothfusz regression equation for temperatures above $26.7^\circ\text{C}$ ($80^\circ\text{F}$) and relative humidity between 0% and 100%:
$$\text{HI} = c_1 + c_2 T + c_3 RH + c_4 T \cdot RH + c_5 T^2 + c_6 RH^2 + c_7 T^2 RH + c_8 T \cdot RH^2 + c_9 T^2 RH^2$$
Applies adjustment factors for low humidity / high temperature and high humidity / moderate temperature regimes.

### 7. False-Alarm Gate & Multi-Sensor Fusion (`decision/falseAlarmGate.ts`, `fusion/sensorFusion.ts`)
- **Persistence Verification**: Isolated anomalous ticks do not trigger high-severity alerts. An event must persist across consecutive evaluation windows.
- **Cross-Domain Correlation**: High heart rate during intense physical activity (high motion RMS) is classified as physiological exertion rather than panic or ventricular tachycardia. Conversely, high heart rate combined with zero motion and elevated ambient heat index increases the heat exhaustion risk score.
- **Emergency SOS Decision**: Recommends triggering the SOS workflow if confirmed fall occurs with sustained immobility, or if severe multi-risk convergence is detected.

---

## Testing

The AI engine includes an automated end-to-end verification script testing all DSP stages:

```bash
# Run from workspace root:
npm run test:ai

# Or run directly:
npx tsx mobile-app/ai-engine/__tests__/aiPipeline.test.ts
```

### Verified Test Cases:
1. **ECG Filter Chain**: Attenuation of 50 Hz noise and DC baseline drift.
2. **Pan-Tompkins Detection**: QRS peak detection and RR interval validation on simulated waveforms.
3. **HR & HRV Computation**: Correct mathematical derivation of BPM, RMSSD, and SDNN.
4. **Motion Classification & Fall Engine**: Rest vs vigorous activity, and 3-stage fall confirmation.
5. **NWS Heat Index**: Validated against NOAA benchmark tables for multiple $(T, RH)$ pairs.
6. **Full Pipeline Orchestration**: Validates `processSensorTick()` output structure and bounds.
7. **SOS Alarm Gating**: Multi-window confirmation under emergency stress conditions.

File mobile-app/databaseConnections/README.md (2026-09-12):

# Database Subsystem — On-Device SQLite Storage

This directory implements the local, zero-cloud SQLite persistence layer for the Sanjeevni mobile application using `expo-sqlite`. It stores real-time physiological vitals, security alerts, emergency contact configurations, and personal baseline statistics directly on the mobile device.

---

## Directory Layout

```text
databaseConnections/
├── database.ts                      # Core SQLite engine, Schema v4 migrations, CRUD & pruning
├── database.web.ts                  # Web-safe mock fallback for browser execution
├── __tests__/
│   └── databaseSchema.test.ts       # 12-test automated verification suite
└── README.md                        # This specification
```

---

## Database Architecture (Schema v4)

Database file name: `sanjeevni.db`

### Tables & Indices

#### 1. `readings`
Stores continuous, downsampled vital telemetry and sensor metrics streamed from the ESP32.

```sql
CREATE TABLE IF NOT EXISTS readings (
  id INTEGER PRIMARY KEY AUTOINCREMENT,
  user_id TEXT NOT NULL DEFAULT 'offline_local',
  timestamp TEXT NOT NULL,
  sensor_type TEXT NOT NULL,
  value REAL NOT NULL,
  source TEXT NOT NULL,
  synced INTEGER DEFAULT 0
);

CREATE INDEX IF NOT EXISTS idx_readings_sensor_timestamp 
  ON readings(sensor_type, timestamp);
CREATE INDEX IF NOT EXISTS idx_readings_user_sensor_ts 
  ON readings(user_id, sensor_type, timestamp);
```

- `sensor_type`: Standardized identifiers (`HEART_RATE`, `ECG_SQI`, `HRV_RMSSD`, `TEMPERATURE`, `HUMIDITY`, `HEAT_INDEX`, `AQI_RAW`, `SKIN_MOISTURE`, `MOTION_MAGNITUDE`, `STEP_COUNT`).
- `source`: Origin marker (`hardware_ble`, `ai_engine`, or `simulation`).
- `synced`: 0 = local only, 1 = synced (reserved for future optional manual exports).

#### 2. `alerts`
Stores critical physiological thresholds, fall events, and environmental hazard triggers.

```sql
CREATE TABLE IF NOT EXISTS alerts (
  id INTEGER PRIMARY KEY AUTOINCREMENT,
  user_id TEXT NOT NULL DEFAULT 'offline_local',
  timestamp TEXT NOT NULL,
  category TEXT NOT NULL,
  severity TEXT CHECK(severity IN ('LOW', 'MODERATE', 'HIGH', 'CRITICAL')) NOT NULL,
  message TEXT NOT NULL,
  acknowledged INTEGER DEFAULT 0
);

CREATE INDEX IF NOT EXISTS idx_alerts_timestamp ON alerts(timestamp);
CREATE INDEX IF NOT EXISTS idx_alerts_user_ts ON alerts(user_id, timestamp);
```

#### 3. `user_profile`
Persists the active user's demographic parameters, emergency contact details, and baseline vulnerability flags.

```sql
CREATE TABLE IF NOT EXISTS user_profile (
  user_id TEXT PRIMARY KEY,
  name TEXT DEFAULT 'Sanjeevni User',
  email TEXT DEFAULT 'user@sanjeevni.health',
  pin TEXT DEFAULT '',
  age INTEGER DEFAULT 25,
  gender TEXT DEFAULT 'Other',
  height_cm REAL DEFAULT 170,
  weight_kg REAL DEFAULT 65,
  blood_group TEXT DEFAULT 'O+',
  medical_condition TEXT DEFAULT 'None',
  emergency_name TEXT DEFAULT 'Emergency Contact',
  emergency_phone TEXT DEFAULT '+91 98765 43210',
  is_logged_in INTEGER DEFAULT 1,
  baseline_values TEXT,
  vulnerability_flags TEXT,
  emergency_contact TEXT
);
```

#### 4. `rolling_baseline`
Maintains running statistical aggregates (Welford's online mean and variance) for individual user baseline calibration.

```sql
CREATE TABLE IF NOT EXISTS rolling_baseline (
  user_id TEXT NOT NULL,
  metric TEXT NOT NULL,
  mean REAL NOT NULL,
  variance REAL NOT NULL,
  count INTEGER NOT NULL,
  last_updated TEXT NOT NULL,
  PRIMARY KEY (user_id, metric)
);
```

---

## Data Lifecycle & Retention

To prevent unbounded flash memory growth on wearable mobile hosts:

1. **7-Day Rolling Pruning (`pruneOldReadings`)**:
   Deletes raw high-frequency `readings` older than 7 days based on ISO-8601 timestamps:
   ```sql
   DELETE FROM readings WHERE timestamp < datetime('now', '-7 days');
   ```
2. **6-Month Rollup Downsampling (`rollupHistoricalData`)**:
   Rolls up historical data into hourly averages before purging long-term raw records.
3. **Multi-User Isolation (`normalizeUserId`)**:
   Every query filters strictly by `user_id`. When unauthenticated or in offline guest mode, defaults to `'offline_local'`.

---

## Testing & Verification

The database layer includes 12 automated unit tests covering table creation, bounded enum constraints, index efficiency, CRUD operations, multi-user partitioning, and retention pruning:

```bash
# Run from workspace root:
npm run test:db

# Or run directly inside mobile-app:
npx tsx databaseConnections/__tests__/databaseSchema.test.ts
```

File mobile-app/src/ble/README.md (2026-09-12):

# Sanjeevni BLE / Hardware Communication Module

> **Sub-repo integration guide for [SIH_GLAH10_BrajCoders](https://github.com/Sahil073/SIH_GLAH10_BrajCoders)**  
> This module encapsulates the complete Bluetooth Low Energy (BLE 4.2 / 5.0) communication pipeline between the ESP32 Sensor Hub and the Sanjeevni React Native mobile app.

---

## Architecture & File Layout

```text
src/ble/
├── index.ts                 # Public barrel export for the entire BLE module
├── types.ts                 # Authoritative contracts for Sensors 1–5 & BLE state
├── packetParser.ts          # Stream reassembly buffer, Base64 decoding, JSON/CSV parser
├── bleManager.ts            # Nordic UART Service (NUS) driver, auto-reconnect, simulation
├── bleStore.ts              # Reactive Zustand-like state store & useBle hook
├── hooks/
│   └── useBleConnection.ts  # Clean presentational hook for UI screens
└── README.md                # This integration document
```

---

## Hardware Protocol Specification

- **GATT Service:** Nordic UART Service (NUS)
  - **Service UUID:** `6E400001-B5A3-F393-E0A9-E50E24DCCA9E`
  - **RX Characteristic (Write):** `6E400002-B5A3-F393-E0A9-E50E24DCCA9E`
  - **TX Characteristic (Notify):** `6E400003-B5A3-F393-E0A9-E50E24DCCA9E`
- **Framing:** Newline-delimited (`\n`) JSON packets conforming to schema version 1 (`"v": 1`).
- **Chunking:** The ESP32 firmware breaks high-frequency payloads (e.g. BioAmp EXG 128 samples) into chunks. `StreamPacketParser` safely reassembles them across chunk boundaries before parsing.

### Supported Sensors

| Sensor ID | Sensor Name | Telemetry Payload |
| :--- | :--- | :--- |
| `1` | **BioAmp EXG Pill** | `samples: number[]` (128 integers @ 500 Hz for ECG/EMG) |
| `2` | **ADXL345** | `data: { x, y, z }` (3-axis acceleration in $m/s^2$) |
| `3` | **DHT11** | `data: { temperature, humidity }` (°C and % RH) |
| `4` | **MQ135** | `data: { raw }` (12-bit ADC air quality reading) |
| `5` | **Soil Moisture** | `data: { raw }` (12-bit ADC galvanic/sweat moisture) |

---

## Required Dependencies in Upstream Repo

Ensure the following packages are in `package.json`:

```json
{
  "dependencies": {
    "react-native-ble-plx": "^3.2.1",
    "base-64": "^1.0.0"
  },
  "devDependencies": {
    "@types/base-64": "^1.0.2"
  }
}
```

### Android Permissions (`app.json`)

```json
{
  "expo": {
    "android": {
      "permissions": [
        "android.permission.BLUETOOTH",
        "android.permission.BLUETOOTH_ADMIN",
        "android.permission.BLUETOOTH_CONNECT",
        "android.permission.BLUETOOTH_SCAN",
        "android.permission.ACCESS_FINE_LOCATION",
        "android.permission.ACCESS_COARSE_LOCATION"
      ]
    },
    "plugins": [
      [
        "react-native-ble-plx",
        {
          "isBackgroundEnabled": false,
          "modes": ["peripheral", "central"],
          "bluetoothAlwaysPermission": "Allow Sanjeevni to connect to ESP32 BLE health sensors"
        }
      ]
    ]
  }
}
```

---

## Usage Examples

### 1. In UI Connection Screens (`connect-device.tsx`)

```tsx
import { useBleConnection } from "@/ble";

export default function ConnectDeviceScreen() {
  const { status, discoveredDevices, connectDevice, startScan } =
    useBleConnection();

  return (
    <View>
      <Text>Status: {status}</Text>
      {discoveredDevices.map((device) => (
        <TouchableOpacity
          key={device.id}
          onPress={() => connectDevice(device.id)}
        >
          <Text>{device.name}</Text>
        </TouchableOpacity>
      ))}
    </View>
  );
}
```

### 2. In Health Telemetry Adapters (`useDashboardData.ts`)

```tsx
import { useBle } from "@/ble";

export function useDashboardData() {
  const { sensorData, connectionStatus } = useBle();

  // Ingest BioAmp EXG samples
  const exgSamples = sensorData.exg.samples;
  // Ingest DHT11 ambient conditions
  const temperature = sensorData.dht.temperature;
  const humidity = sensorData.dht.humidity;

  return {
    /* transformed vitals */
  };
}
```

### 3. Direct Service Access (Background / SOS Tasks)

```tsx
import { bleService } from "@/ble";

// Trigger automatic hands-free scanning & reconnect
await bleService.startAutoConnect();

// Check native hardware availability
const isSupported = bleService.isBleSupported();
```

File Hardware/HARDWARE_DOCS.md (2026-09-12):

# Hardware Documentation — ESP32 Sensor System

> **Project:** SIH GLAH10 BrajCoders
> **Target MCU:** Classic ESP32 (ESP32-WROOM / DevKit V1), ESP32-S3, ESP32-C3, Arduino framework
> **Transport:** Bluetooth Low Energy (BLE GATT) — Nordic UART Service (NUS)
> **Full integration sketch:** [`Hardware/ESP32_Sensor_Hub/ESP32_Sensor_Hub.ino`](ESP32_Sensor_Hub/ESP32_Sensor_Hub.ino)

---

## Table of Contents

1. [System Overview](#1-system-overview)
2. [MCU — ESP32](#2-mcu--esp32)
3. [Sensors](#3-sensors)
   - [3.1 BioAmp EXG Pill](#31-bioamp-exg-pill)
   - [3.2 ADXL345](#32-adxl345)
   - [3.3 DHT11](#33-dht11)
   - [3.4 MQ135](#34-mq135)
   - [3.5 Soil Moisture Sensor](#35-soil-moisture-sensor)
4. [Pin Assignments (Integration)](#4-pin-assignments-integration)
5. [Libraries Required](#5-libraries-required)
6. [Device Testing Sketches](#6-device-testing-sketches)
7. [Full Integration — ESP32_Sensor_Hub](#7-full-integration--esp32_sensor_hub)
8. [Sampling Rates and Transmission Schedule](#8-sampling-rates-and-transmission-schedule)
9. [Bluetooth Data Protocol](#9-bluetooth-data-protocol)
10. [JSON Packet Reference](#10-json-packet-reference)
11. [Field Sample Data Analysis (`sample_data.txt`)](#11-field-sample-data-analysis-sample_datatxt)
12. [Power Distribution, Battery Sizing & Thermal Analysis](#12-power-distribution-battery-sizing--thermal-analysis)
13. [Custom PCB Hardware Reference](#13-custom-pcb-hardware-reference)
14. [Known Notes and Caveats](#14-known-notes-and-caveats)

---

## 1. System Overview

ESP32 Sensor System Architecture

The ESP32 acquires sensor data continuously regardless of BLE connection
state. BLE transmission is conditional — if no client is connected, data
is silently discarded (bounded buffer, no unbounded queuing). When a client
connects and subscribes to the TX characteristic notifications, structured
newline-delimited JSON packets are streamed. If a client disconnects, the ESP32
automatically resumes BLE advertising.

---

## 2. MCU — ESP32

| Property | Value |
| --- | --- |
| Chip | ESP32 (Xtensa LX6 dual-core), ESP32-S3, ESP32-C3 |
| Board | ESP32-WROOM / DevKit V1 |
| Framework | Arduino |
| Bluetooth | Bluetooth Low Energy (BLE 4.2 / 5.0 GATT Server) |
| BLE Profile | Nordic UART Service (NUS) |
| ADC resolution  | 12-bit (0–4095 across 0–3.3 V) |
| I2C | Remappable; SDA=GPIO 21, SCL=GPIO 22 |
| USB Serial baud | 115200 |

> **Advantage of BLE:** Unlike legacy Bluetooth Classic (SPP) which was strictly
> restricted to the original dual-core ESP32 chip, BLE is natively supported across
> the modern ESP32 family (ESP32, ESP32-S3, ESP32-C3) and supports direct
> connections from iOS, Android, macOS, Linux, and Web Bluetooth in modern browsers.

---

## 3. Sensors

### 3.1 BioAmp EXG Pill

| Property | Value |
| --- | --- |
| Manufacturer | Upside Down Labs |
| Type | Biopotential instrumentation amplifier front-end |
| Signals | EMG, ECG, EOG, EEG (depending on electrode placement) |
| Interface | Analog voltage output |
| Supply voltage | 3.3 V |
| Output pin | GPIO 34 (input-only ADC1_CH6) |
| ADC resolution | 12-bit → 0–4095 |
| Output unit | Raw ADC integer (not µV or mV) |

**Wiring:**

| EXG Pill Pin | ESP32 Pin |
| --- | --- |
| VCC | 3.3 V |
| GND | GND |
| OUT | GPIO 34 |

**Notes:**

- GPIO 34 is an input-only pin — no pull-up, no output driver.
- The raw ADC value represents the amplified biopotential from electrodes.
  No biomedical interpretation or unit conversion is performed.
- The EXG Pill requires body electrodes connected per Upside Down Labs
  documentation for the target signal type (EMG/ECG/EOG/EEG).

---

### 3.2 ADXL345

| Property | Value |
| --- | --- |
| Manufacturer | Analog Devices |
| Type | 3-axis digital accelerometer |
| Interface | I2C (or SPI — I2C used here) |
| I2C address | 0x53 (SDO=GND) or 0x1D (SDO=HIGH) |
| Supply voltage | 3.3 V |
| Measurement range | ±2G (configured in code; options: ±2G/±4G/±8G/±16G) |
| Output unit | m/s² (via Adafruit unified sensor API) |
| SDA pin | GPIO 21 |
| SCL pin | GPIO 22 |

**Wiring:**

| ADXL345 Pin | ESP32 Pin |
| --- | --- |
| VCC | 3.3 V |
| GND | GND |
| SDA | GPIO 21 |
| SCL | GPIO 22 |
| SDO | GND (sets I2C address to 0x53) |
| CS | 3.3 V (selects I2C mode) |

**Notes:**

- `Wire.begin(21, 22)` is called explicitly to configure the I2C pins.
- The Adafruit ADXL345 library returns acceleration as a `sensors_event_t`
  struct — values are in m/s² with 2 decimal places in transmitted packets.
- If `adxl.begin()` returns false at startup, the sensor is marked unavailable
  and all ADXL-related code skips gracefully; other sensors continue running.

---

### 3.3 DHT11

| Property | Value |
| --- | --- |
| Type | Digital temperature and humidity sensor |
| Interface | Single-wire proprietary DHT protocol |
| Supply voltage | 3.3 V (or 5 V with a regulator module)  |
| Data pin | GPIO 4 |
| Temperature range | 0–50 °C ± 2 °C, resolution 1 °C |
| Humidity range | 20–80 % RH ± 5 % RH, resolution 1 % |
| Min sample interval | 1–2 seconds |
| Library | `DHT.h` (Adafruit DHT sensor library) |

**Wiring:**

| DHT11 Pin | ESP32 Pin |
| --- | --- |
| VCC | 3.3 V |
| DATA | GPIO 4 |
| GND | GND |

**Notes:**

- If using a bare DHT11 (not a breakout module), add a 10 kΩ pull-up
  resistor between the DATA pin and VCC.
- Readings are validated with `isnan()`. If a read fails (returns NaN),
  the packet is discarded and an error is printed to USB Serial.
- Do not poll faster than every 2 seconds — the DHT11 requires recovery time.

---

### 3.4 MQ135

| Property | Value |
| --- | --- |
| Type | Gas detection sensor (multi-gas: CO₂, NH₃, benzene, alcohol, smoke) |
| Interface | Analog voltage output (AO pin) |
| Supply voltage  | **5 V** (heater element requires 5 V) |
| AO output range | 0–5 V max (varies by gas concentration) |
| ADC pin | GPIO 35 (input-only ADC1_CH7) |
| ADC resolution  | 12-bit → 0–4095 |
| Output unit | Raw ADC integer (not ppm) |
| Warm-up time | 24–48 h for full stabilisation; ≥3–5 min after power-on |

**Wiring:**

| MQ135 Pin | ESP32 Pin |
| --- | --- |
| VCC | 5 V |
| GND | GND |
| AO | GPIO 35 |
| DO | Not connected |

**Notes:**

- The MQ135 heater runs at 5 V — the AO output may swing above 3.3 V at
  high gas concentrations. Verify your specific module's output voltage range
  before connecting directly to an ESP32 GPIO (max 3.3 V).
  Some breakout modules include a voltage divider on the AO line.
- No ppm conversion or calibration is implemented. Converting raw ADC to ppm
  requires the sensor's Rs/R0 ratio and calibration with a reference gas.
- The test sketch (`MQ135_Bluetooth.ino`) uses GPIO 34. The full integration
  (`ESP32_Sensor_Hub.ino`) uses GPIO 35. Both are input-only ADC pins.

---

### 3.5 Soil Moisture Sensor

| Property | Value |
| --- | --- |
| Type | Capacitive or resistive soil moisture module |
| Interface | Analog voltage output (AO pin) |
| Supply voltage | 3.3 V or 5 V (check module) |
| ADC pin | GPIO 32 (ADC1_CH4; supports both ADC and digital I/O) |
| ADC resolution | 12-bit → 0–4095 |
| Output unit | Raw ADC integer (not % moisture) |

**Wiring:**

| Sensor Pin | ESP32 Pin |
| --- | --- |
| VCC | 3.3 V (or 5 V) |
| GND | GND |
| AO | GPIO 32 |

**ADC value interpretation:**

| Module type | Higher ADC value | Lower ADC value |
| --- | --- | --- |
| Capacitive  | Drier (lower output voltage) | Wetter (higher output voltage) |
| Resistive | Wetter (lower resistance) | Drier (higher resistance) |

**Notes:**

- No dry/wet calibration constants are defined. To express readings as a
  moisture percentage, record ADC values in known fully-dry and fully-saturated
  soil conditions with your specific sensor, then apply linear mapping.
- Capacitive sensors are preferred — resistive probes corrode over time.
- The test sketch (`Moisture_Bluetooth.ino`) uses GPIO 34.
  The full integration (`ESP32_Sensor_Hub.ino`) uses GPIO 32.

---

## 4. Pin Assignments (Integration)

These are the **definitive pin assignments** for `ESP32_Sensor_Hub.ino`.
Individual test sketches may differ — see their headers.

| Sensor | Signal | ESP32 GPIO | Pin type |
| --- | --- | --- | --- |
| BioAmp EXG Pill | Analog out | 34 | Input-only ADC1 |
| ADXL345 | SDA | 21 | I2C (remappable) |
| ADXL345 | SCL | 22 | I2C (remappable) |
| DHT11 | Data | 4 | Digital I/O |
| MQ135 | Analog out | 35 | Input-only ADC1 |
| Soil Moisture | Analog out | 32 | ADC1 + digital I/O |

---

## 5. Libraries Required

| Library | Used by | Source |
| --- | --- | --- |
| `BLEDevice`, `BLEServer`, `BLEUtils`, `BLE2902` | All BLE sketches + hub | ESP32 Arduino core (built-in) |
| `Wire` | ADXL345 | ESP32 Arduino core (built-in) |
| `Adafruit_Sensor` | ADXL345 | Arduino Library Manager |
| `Adafruit_ADXL345_U` | ADXL345 | Arduino Library Manager |
| `DHT.h` (Adafruit DHT sensor library) | DHT11 | Arduino Library Manager |
| `ArduinoJson` | ESP32_Sensor_Hub only  | Arduino Library Manager |

> The BLE stack (`BLEDevice`, `BLEServer`, etc.) and `Wire` are bundled directly
> with the ESP32 Arduino core — no external installation is needed for them.

---

## 6. Device Testing Sketches

The repository provides a modular, **two-tier testing suite** located in [`Hardware/Device-Testing/`](Device-Testing/):

1. **Tier 1 — Standalone Diagnostic Sketches (Zero BLE overhead):**
   Print human-readable physical metrics or plain integer streams to the **USB Serial Monitor / Serial Plotter** (115200 baud). Used to verify electrical continuity, pin wiring, I2C addressing, and sensor calibration before introducing wireless complexity.
2. **Tier 2 — Component-Level BLE Protocol v1 Sketches:**
   Stream JSON packets using the **exact same Protocol v1 JSON format** as the production hub (`ESP32_Sensor_Hub.ino`). These sketches can connect directly to the **mobile app**, **Web Bluetooth dashboard**, or generic BLE terminal tools (_nRF Connect_ / _Serial Bluetooth Terminal_).

> For detailed wiring diagrams, verification steps, and terminal output examples for each test, see [`Hardware/Device-Testing/DEVICE_TESTING_GUIDE.md`](Device-Testing/DEVICE_TESTING_GUIDE.md).

### 6.1 Tier 1: Standalone Hardware Diagnostics (USB Serial Only)

| Sketch | Folder | Target Sensor | Pin / Interface | Baud Rate | Verification Target |
| --- | --- | --- | --- | --- | --- |
| `LED.ino` | `LED/` | Onboard Blue LED | GPIO 2 | 115200 | ESP32 bootloader, clock crystal, and GPIO driver sanity test (0.5 Hz blink) |
| `Bioamp_EXG.ino`  | `Bioamp_EXG/` | BioAmp EXG Pill | GPIO 34 (ADC1)  | 115200 | Raw ADC waveform plotting in Arduino Serial Plotter (lead-off: 4095; baseline: ~1.65 V) |
| `ADXL345.ino` | `ADXL345/` | ADXL345 3-Axis Accel| I2C (21/22) | 115200 | I2C detection (0x53), X/Y/Z m/s², and vector magnitude $|\vec{a}| \approx 9.8\text{ m/s}^2$ |
| `DHT11.ino` | `DHT11/` | DHT11 Temp & Hum | GPIO 4 (1-Wire) | 115200 | Ambient Temperature (°C), Relative Humidity (% RH), and Heat Index calculation |
| `MQ135.ino` | `MQ135/` | MQ135 Gas Sensor | GPIO 35 (ADC1)  | 115200 | 10-sample ADC rolling average, voltage conversion (0–3.3 V), baseline AQI status |
| `Moisture.ino` | `Moisture/` | Soil Moisture Probe | GPIO 32 (ADC1)  | 115200 | 10-sample ADC rolling average and calibrated moisture percentage (0–100% scale) |

### 6.2 Tier 2: Component-Level BLE Protocol v1 Sketches

All Tier 2 sketches implement the standard Nordic UART Service (NUS) UUIDs (`6E400001-...`) and stream compact newline-delimited JSON identical to the final hub protocol:

| Sketch | Folder | Sensor / Feature | BLE Device Name | Protocol Packet Schema | Rate |
| --- | --- | --- | --- | --- | --- |
| `Bluetooth.ino` | `Bluetooth/` | BLE NUS Link | `ESP32_TEST_BLE` | `TEST DATA: <seq>\n` (ASCII connectivity test) | 1 Hz |
| `Bioamp_EXG_Bluetooth.ino` | `Bioamp_EXG_Bluetooth/` | BioAmp EXG | `ESP32_EXG_BLE` | `{"v":1,"sensor":1,"seq":N,"ts":T,"rate":500,"samples":[...]}` | 3.9 Hz |
| `ADXL_Bluetooth.ino` | `ADXL_Bluetooth/` | ADXL345 Accel | `ESP32_ADXL_BLE` | `{"v":1,"sensor":2,"seq":N,"ts":T,"data":{"x":..,"y":..,"z":..}}` | 25 Hz  |
| `DHT_Bluetooth.ino` | `DHT_Bluetooth/` | DHT11 Temp/Hum | `ESP32_DHT11_BLE` | `{"v":1,"sensor":3,"seq":N,"ts":T,"data":{"temperature":..,"humidity":..}}` | 0.5 Hz |
| `MQ135_Bluetooth.ino` | `MQ135_Bluetooth/` | MQ135 Gas | `ESP32_MQ135_BLE` | `{"v":1,"sensor":4,"seq":N,"ts":T,"data":{"raw":..}}` | 1 Hz |
| `Moisture_Bluetooth.ino` | `Moisture_Bluetooth/` | Soil Moisture | `ESP32_SOIL_BLE` | `{"v":1,"sensor":5,"seq":N,"ts":T,"data":{"raw":..}}` | 0.5 Hz |

> **Pin Consistency:** All Tier 2 BLE sketches use the canonical integration pins (EXG: GPIO 34, ADXL: 21/22, DHT11: GPIO 4, MQ135: GPIO 35, Soil: GPIO 32) matching `ESP32_Sensor_Hub.ino`. Safe 128-byte BLE chunking is implemented across all sketches to prevent GATT notify buffer overflow.

---

## 7. Full Integration — ESP32_Sensor_Hub

**File:** [`Hardware/ESP32_Sensor_Hub/ESP32_Sensor_Hub.ino`](ESP32_Sensor_Hub/ESP32_Sensor_Hub.ino)

### Architecture

- **Non-blocking multi-rate scheduler** using `millis()` and `micros()`.
- **No `delay()` in `loop()`** — all rate control is timer-based.
- EXG acquisition is the highest-priority task (500 Hz via `micros()`), checked on every loop iteration.
- All sensors acquire data independently of BLE connection state.
- BLE transmission is guarded by `if (deviceConnected)`.
- **BLE GATT Server** implements the standard **Nordic UART Service (NUS)**.
- **Auto-advertising restart**: When a client disconnects, `pServer->startAdvertising()` is triggered automatically to allow seamless reconnection.
- **Large packet handling & MTU**: Calls `BLEDevice::setMTU(517)` during initialization and employs a safe 128-byte chunked transmission loop (`sendJson()`) with 2 ms yield to prevent notify buffer congestion for large EXG JSON payloads (~700–800 bytes).
- JSON packets end with `\n` (newline) as the packet delimiter.

### Sensor ID Enum (protocol-fixed — do not change values)

```cpp
enum class SensorId : uint8_t
{
    EXG           = 1,
    ADXL345       = 2,
    DHT11         = 3,
    MQ135         = 4,
    SOIL_MOISTURE = 5
};
```

### Sequence Numbers

Each sensor has its own independent sequence counter:

| Variable | Sensor |
| --- | --- |
| `exgSequence` | BioAmp EXG Pill |
| `adxlSequence`  | ADXL345 |
| `dhtSequence` | DHT11 |
| `mq135Sequence` | MQ135 |
| `soilSequence`  | Soil Moisture |

Sequence numbers allow the receiving application to detect missing packets
per sensor independently.

### Timestamp

All packets include `"ts"` — the ESP32 uptime in milliseconds (`millis()`).

> **This is NOT a Unix wall-clock timestamp.**
> It is milliseconds since the ESP32 last booted.
> The backend application must associate it with wall-clock time if needed
> (e.g., by recording the first-packet wall-clock time and offsetting).

---

## 8. Sampling Rates and Transmission Schedule

| Sensor | ADC / Acquisition rate | Averaging | Bluetooth TX rate | Buffer |
| --- | --- | --- | --- | --- |
| BioAmp EXG Pill | **500 Hz** (2 ms interval, `micros()`-based) | None | 1 packet per 128 samples (~3.9 Hz) | 128 samples  |
| ADXL345 | **100 Hz** (10 ms, `millis()`-based) | None | **25 Hz** (40 ms gate) | Latest value |
| DHT11 | **0.5 Hz** (2000 ms gate) | None | **0.5 Hz** | — |
| MQ135 | **10 Hz** (100 ms gate) | 10-sample average | **1 Hz** (1000 ms gate) | Running sum  |
| Soil Moisture | **10 Hz** (100 ms gate) | 10-sample average | **0.5 Hz** (2000 ms gate) | Running sum  |

> EXG timing uses `micros()` and fixed-interval advance (`exgLastMicros += EXG_INTERVAL_US`)
> to prevent drift accumulation. All other sensors use `millis()`.

---

## 9. Bluetooth Data Protocol

| Property | Value |
| --- | --- |
| Protocol | Bluetooth Low Energy (BLE 4.2 / 5.0) GATT Server |
| Profile | Nordic UART Service (NUS) |
| Service UUID | `6E400001-B5A3-F393-E0A9-E50E24DCCA9E` |
| RX Char UUID | `6E400002-B5A3-F393-E0A9-E50E24DCCA9E` (Write/WriteWithoutResp) |
| TX Char UUID | `6E400003-B5A3-F393-E0A9-E50E24DCCA9E` (Notify) |
| CCCD Descriptor  | `00002902-0000-1000-8000-00805f9b34fb` (`BLE2902`) |
| Device name | `ESP32_SENSOR_HUB_BLE` |
| MTU Requested | 517 bytes (`BLEDevice::setMTU(517)`) |
| Data format | Compact JSON |
| Packet delimiter | Newline character `\n` |
| Protocol version | `"v": 1` (fixed; present in every packet) |

### Connecting from Client Applications

1. **Android / iOS (Serial Bluetooth Terminal / nRF Connect):**
   - Open app and navigate to **Bluetooth LE** / **BLE Scanner**.
   - Scan and connect to `ESP32_SENSOR_HUB_BLE`.
   - The app detects the Nordic UART Service automatically.
   - Enable notifications on characteristic `6E400003-...` to receive the JSON stream.
2. **Web Bluetooth API (Chrome / Edge):**
   - Request device with filter `services: ['6e400001-b5a3-f393-e0a9-e50e24dcca9e']`.
   - Connect to GATT server, get primary service, get TX characteristic `6e400003-...`, call `startNotifications()`, and attach listener to `characteristicvaluechanged`.
3. **Flutter / React Native:**
   - Use standard BLE plugins (`flutter_blue_plus`, `react-native-ble-plx`) targeting NUS UUIDs.

**Packet structure (all sensors):**

Every packet contains these common fields plus sensor-specific fields:

| Field | Type | Description |
| --- | --- | --- |
| `v` | integer | Protocol version (always `1`) |
| `sensor` | integer | Sensor ID (1–5, see enum above) |
| `seq` | integer | Per-sensor sequence number (0-based, increments per packet) |
| `ts` | integer | ESP32 uptime in milliseconds (NOT Unix time) |

---

## 10. JSON Packet Reference

### Sensor 1 — BioAmp EXG Pill

```json
{
  "v": 1,
  "sensor": 1,
  "seq": 1042,
  "ts": 123456789,
  "rate": 500,
  "samples": [1842, 1845, 1841, 1839, 1843]
}
```

| Field | Description |
| --- | --- |
| `rate` | Acquisition rate in Hz (always `500`) |
| `samples` | Array of 128 raw 12-bit ADC integers (0–4095) |

- Packet is generated once per 128 samples (~256 ms at 500 Hz).
- `samples` values are raw ADC — not physical units (µV, mV).

---

### Sensor 2 — ADXL345

```json
{
  "v": 1,
  "sensor": 2,
  "seq": 123,
  "ts": 123456789,
  "data": {
    "x": 0.12,
    "y": -0.31,
    "z": 9.76
  }
}
```

| Field | Description |
| --- | --- |
| `data.x` | X-axis acceleration in m/s², 2 decimal places |
| `data.y` | Y-axis acceleration in m/s², 2 decimal places |
| `data.z` | Z-axis acceleration in m/s², 2 decimal places |

- Transmitted at ~25 Hz.

---

### Sensor 3 — DHT11

```json
{
  "v": 1,
  "sensor": 3,
  "seq": 123,
  "ts": 123456789,
  "data": {
    "temperature": 28.4,
    "humidity": 64.0
  }
}
```

| Field | Description |
| --- | --- |
| `data.temperature` | Temperature in °C, 1 decimal place |
| `data.humidity` | Relative humidity in % RH, 1 decimal place |

- Transmitted at ~0.5 Hz (every 2 seconds).
- Packet is skipped if the DHT11 read returns NaN.

---

### Sensor 4 — MQ135

```json
{
  "v": 1,
  "sensor": 4,
  "seq": 123,
  "ts": 123456789,
  "data": {
    "raw": 1854
  }
}
```

| Field | Description |
| --- | --- |
| `data.raw` | 10-sample averaged 12-bit ADC value (0–4095) |

- ADC sampled at 10 Hz; averaged over 10 samples before transmission.
- Transmitted at ~1 Hz.
- Value is raw — not ppm.

---

### Sensor 5 — Soil Moisture

```json
{
  "v": 1,
  "sensor": 5,
  "seq": 123,
  "ts": 123456789,
  "data": {
    "raw": 1842
  }
}
```

| Field | Description |
| --- | --- |
| `data.raw` | 10-sample averaged 12-bit ADC value (0–4095) |

- ADC sampled at 10 Hz; averaged over 10 samples before transmission.
- Transmitted at ~0.5 Hz (every 2 seconds).
- Value is raw — no moisture percentage conversion applied.

---

## 11. Field Sample Data Analysis (`sample_data.txt`)

The file [`Hardware/sample_data.txt`](sample_data.txt) contains **1,130 lines** of live telemetry captured from physical hardware streaming over BLE to verify the protocol under realistic conditions. Technical analysis of this telemetry validates several key firmware dynamics:

### 11.1 Multi-Sensor Interleaving and Sequence Integrity
Telemetry confirms seamless multiplexing across the single Nordic UART Service pipe:
- **EXG Burst Cadence (`sensor: 1`):** Transmitted every 128 samples at 500 Hz. Packet timestamps show exactly $\Delta t \approx 256\text{ ms}$ between consecutive packets:
  - Sequence 705 (`ts: 181482`) $\to$ Sequence 706 (`ts: 181738`, $\Delta t = 256\text{ ms}$) $\to$ Sequence 707 (`ts: 181994`, $\Delta t = 256\text{ ms}$).
  - This mathematically proves the precision of the `micros()` accumulator scheduler (`exgLastMicros += EXG_INTERVAL_US`) with zero cumulative timer drift.
- **Motion Cadence (`sensor: 2`):** Transmitted at exactly $\Delta t = 40\text{ ms}$ ($25\text{ Hz}$):
  - Sequence 4518 (`ts: 181483`) $\to$ Sequence 4519 (`ts: 181523`, $\Delta t = 40\text{ ms}$) $\to$ Sequence 4520 (`ts: 181563`, $\Delta t = 40\text{ ms}$).
- **Gas Cadence (`sensor: 4`):** Transmitted at $1\text{ Hz}$ with independent sequence tracking (`seq: 180`, `ts: 181751`, `raw: 906`).
- **Independent Monotonic Sequence Counters:** Sequences for EXG, ADXL, and MQ135 advance strictly monotonically without dropping or reordering packets, enabling the mobile application to detect dropouts on a per-channel basis.

### 11.2 Biopotential Dynamics & Lead-Off Detection
In sequence 709 (`ts: 182506`), the biopotential signal transitions from valid cardiac/muscular waveforms into complete ADC saturation:
```json
{"v":1,"sensor":1,"seq":709,"ts":182506,"rate":500,"samples":[1279,1264,1269,1301,1376,...,2774,3534,4095,4095,4095,4095,...]}
```
- **Physical Meaning:** When dry or wet biopotential electrodes detach from the skin (or lose contact impedance), the instrumentation amplifier's high-impedance inputs float to the positive rail ($V_{DD} = 3.3\text{ V}$). The 12-bit ADC reads maximum full-scale: $4095$.
- **Signal Quality Index (SQI) Trigger:** The mobile app's signal quality engine parses this chunk, flags saturated sample counts $> 10\%$, sets `isLeadOn = false`, and alerts the user on the dashboard to reposition the electrodes.

### 11.3 Accelerometer Posture Vector & Dynamics
Across steady-state frames (e.g. sequence 4518: $x = 1.65, y = -3.61, z = -11.02\text{ m/s}^2$):
$$\|\vec{a}\| = \sqrt{(1.65)^2 + (-3.61)^2 + (-11.02)^2} \approx 11.71\text{ m/s}^2$$
Sequence 4533 ($x = -6.35, y = 7.30, z = -15.02\text{ m/s}^2$):
$$\|\vec{a}\| = \sqrt{(-6.35)^2 + (7.30)^2 + (-15.02)^2} \approx 17.86\text{ m/s}^2$$
- The vector magnitude represents the superposition of gravitational acceleration ($1g \approx 9.81\text{ m/s}^2$) plus user kinetic motion and sensor orientation tilts.
- The high acceleration transients captured in the stream demonstrate that the 25 Hz streaming rate reliably captures physical user motion gestures, tremor spikes, and fall events.

---

## 12. Power Distribution, Battery Sizing & Thermal Analysis

To ensure continuous, field-reliable operation as a wearable health & environmental monitor, the power budget and battery capacity have been calculated for **8–12 hours of continuous streaming**.

### 12.1 Subsystem Current Draw Breakdown

| Subsystem / Component | Operating Voltage | Active Current Draw | Duty Cycle | Average Current @ Nominal Rail | Equivalent Battery Draw (3.7V LiPo) |
| --- | --- | --- | --- | --- | --- |
| **ESP32 Dual-Core + BLE TX** | 3.3 V | 95 mA | 100% | 95.0 mA | ~100.0 mA (via low-dropout LDO) |
| **BioAmp EXG Pill Front-End**| 3.3 V | 2.5 mA | 100% | 2.5 mA | ~2.6 mA |
| **ADXL345 Accelerometer** | 3.3 V | 140 µA | 100% | 0.14 mA | ~0.15 mA |
| **DHT11 Temp / Humidity** | 3.3 V | 1.5 mA | Intermittent| 0.2 mA | ~0.2 mA |
| **Capacitive Soil Moisture** | 3.3 V | 5.0 mA | Intermittent| 1.0 mA | ~1.1 mA |
| **MQ135 Heating Element** | **5.0 V** | 150 mA | 100% | 150.0 mA | **~245.0 mA** (via 85% boost conv.) |
| **Total System Draw (Cont.)**| — | — | — | — | **~349.0 mA** (~1.29 W) |

### 12.2 Battery Capacity Calculations (Continuous Heating)

Assuming a standard single-cell Lithium-Polymer (LiPo) or 18650 Li-ion battery (nominal $3.7\text{ V}$, cutoff $3.2\text{ V}$, DC-DC boost efficiency $\eta \approx 85\%$, and 20% safety / aging headroom):

1. **Target: 8 Hours Continuous Operation**
   $$C_{\text{req}} = I_{\text{batt}} \times t \times \text{Safety Factor} = 349\text{ mA} \times 8\text{ h} \times 1.20 \approx \mathbf{3,350\text{ mAh}}$$
   - *Hardware recommendation:* A single **3,500 mAh** flat-pack LiPo pouch cell or dual 18650 cells (e.g., $2 \times 1,800\text{ mAh} = 3,600\text{ mAh}$ in parallel).

2. **Target: 12 Hours Continuous Operation**
   $$C_{\text{req}} = 349\text{ mA} \times 12\text{ h} \times 1.20 \approx \mathbf{5,025\text{ mAh}}$$
   - *Hardware recommendation:* Dual parallel 18650 Li-ion cells (e.g., $2 \times 2,600\text{ mAh} = \mathbf{5,200\text{ mAh}}$), providing comfortably >12.5 hours of uninterrupted telemetry.

### 12.3 Power Optimization: MQ135 Duty-Cycling Strategy
The MQ135 internal tin dioxide ($SnO_2$) heating coil is by far the largest energy consumer, accounting for **~70% of total system power**. 
In battery-constrained field deployments:
- Rather than leaving the heater permanently energized, the 5V heater rail can be switched via a P-channel MOSFET (e.g., AO3401) driven by an ESP32 GPIO.
- Heating for **20 seconds** prior to reading once every 2 minutes reduces the MQ135 average current from 150 mA down to $\sim 25\text{ mA}$.
- **Result:** Overall battery draw drops to $\sim 128\text{ mA}$, extending an 8-hour battery pack to **over 22 hours** of runtime on a single compact 2,600 mAh 18650 cell.

### 12.4 Thermal Management
- The MQ135 heater dissipates $\approx 750\text{ mW}$ of thermal energy ($5\text{ V} \times 150\text{ mA}$).
- In the Sanjeevni PCB layout, thermal isolation slots and component separation keep the MQ135 physically distanced from the BioAmp EXG operational amplifier circuitry to prevent biopotential drift and thermal junction noise ($1/f$ noise).

---

## 13. Custom PCB Hardware Reference

The system has been synthesized into an integrated, production-grade custom PCB layout located in [`Hardware/Sanjeevni_PCB/`](Sanjeevni_PCB/):

- **Complete Engineering Guide:** Refer to [`Hardware/Sanjeevni_PCB/PCB_Design_Guide.md`](Sanjeevni_PCB/PCB_Design_Guide.md) for detailed trace widths, impedance matching, DRC rules, and manufacturing specifications.
- **Schematic Source:** [`Hardware/Sanjeevni_PCB/Sanjeevni_PCB.kicad_sch`](Sanjeevni_PCB/Sanjeevni_PCB.kicad_sch) (PDF export: [`PCB schema.pdf`](Sanjeevni_PCB/PCB%20schema.pdf))
- **PCB Layout Source:** [`Hardware/Sanjeevni_PCB/Sanjeevni_PCB.kicad_pcb`](Sanjeevni_PCB/Sanjeevni_PCB.kicad_pcb) (PDF export: [`PCB design.pdf`](Sanjeevni_PCB/PCB%20design.pdf))
- **Schematic Source:** [`Hardware/Sanjeevni_PCB/Sanjeevni_PCB.kicad_sch`](Sanjeevni_PCB/Sanjeevni_PCB.kicad_sch) (PDF export: [`PCB_Schematic.pdf`](Sanjeevni_PCB/PCB_Schematic.pdf))
- **PCB Layout Source:** [`Hardware/Sanjeevni_PCB/Sanjeevni_PCB.kicad_pcb`](Sanjeevni_PCB/Sanjeevni_PCB.kicad_pcb) (PDF export: [`PCB_Design.pdf`](Sanjeevni_PCB/PCB_Design.pdf))
- **Stackup & Geometry:**
  - 2-layer FR4 standard process (1.6 mm thickness, 1 oz / $35\text{ µm}$ copper foil).
  - Dedicated bottom ground plane with analog star-grounding under the BioAmp EXG instrumentation node.
  - 15 mm copper-free keepout zone around the ESP32 2.4 GHz inverted-F onboard antenna to prevent BLE RF attenuation.
  - Dedicated LDO and step-up boost regulators providing independent 3.3 V logic and 5.0 V heating rails.

---

## 14. Known Notes and Caveats

| Item | Detail |
| --- | --- |
| **MQ135 voltage** | The MQ135 AO output can exceed 3.3 V. Verify your module's output range before connecting to ESP32. |
| **MQ135 warm-up** | Allow at least 3–5 minutes after power-on; 24–48 hours for full stabilisation. |
| **Pin assignments** | All unified test sketches now default to canonical pins (GPIO 35 for MQ135, GPIO 32 for Moisture), with legacy GPIO 34 test wiring noted in headers. |
| **DHT11 pull-up** | Bare DHT11 (not a module) needs a 10 kΩ pull-up between DATA and VCC. |
| **`ts` is NOT Unix time** | All `"ts"` values are `millis()` uptime. Record wall-clock time of first connection on the receiving side. |
| **BLE Cross-Platform Support** | Unlike Classic Bluetooth (SPP), BLE works across iOS, Android, macOS, Linux, and Windows. It is also compatible with ESP32, ESP32-S3, and ESP32-C3 chips. |
| **BLE Client Notification** | Clients must enable notifications (CCCD 0x2902) on TX characteristic `6E400003-...` to receive the data stream. |
| **Large EXG JSON streaming** | EXG arrays (~800 B) are transmitted in 128-byte BLE notification chunks with 2 ms yields to prevent notify buffer congestion on any MTU size. |
| **EXG signal quality** | Electrode contact quality, EMI, and power supply noise directly affect EXG ADC readings. Lead-Off saturation occurs at ADC = 4095. |
| **Soil calibration** | Dry/wet ADC endpoints vary between sensor modules. Calibrate with your specific sensor in known conditions before deriving a percentage. |
| **ADXL345 I2C address** | Default address is 0x53 (SDO=GND). Pull SDO HIGH to use 0x1D if address conflicts with another device. |

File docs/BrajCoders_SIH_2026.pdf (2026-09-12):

# SMART INDIA HACKATHON 2026

# SANJEEVNI

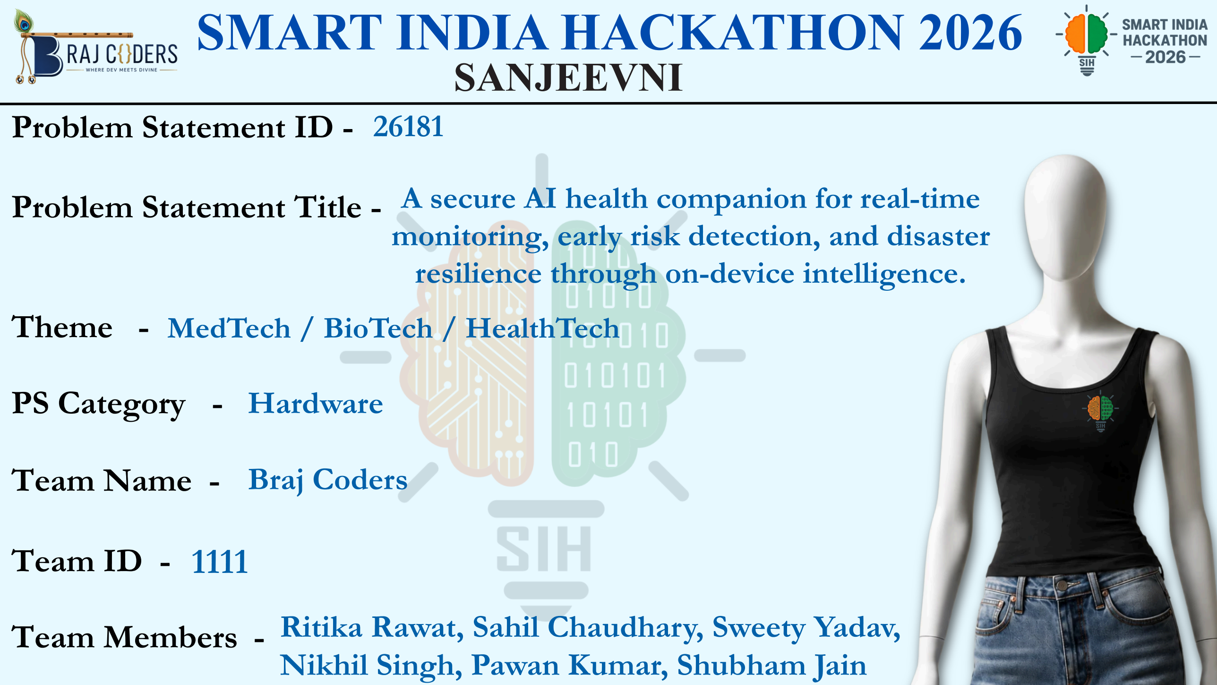
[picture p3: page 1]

# Problem Statement ID -

# Problem Statement Title -

# Theme -

# PS Category -

# Team Name -

# Team ID -

# Team Members -

# A secure AI health companion for real-time monitoring, early risk detection, and disaster

resilience through on-device intelligence.

# MedTech / BioTech / HealthTech

26181

# Hardware

# Braj Coders

Ritika Rawat, Sahil Chaudhary, Sweety Yadav,

# Nikhil Singh, Pawan Kumar, Shubham Jain

1111

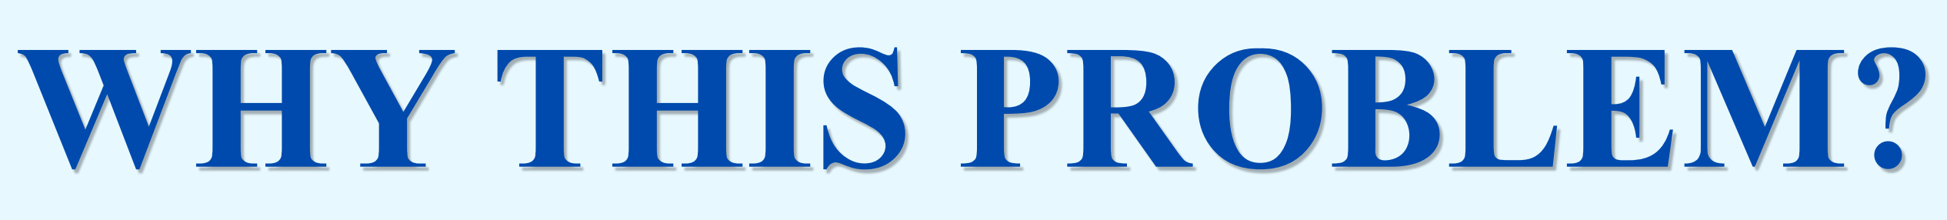
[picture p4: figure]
WHY THIS PROBLEM?
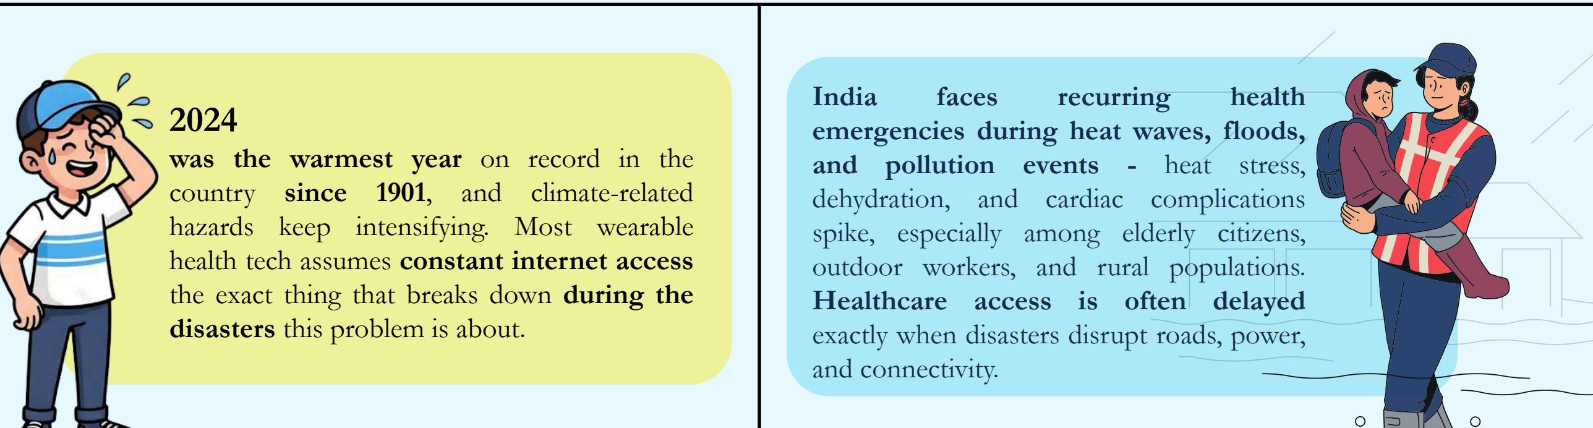
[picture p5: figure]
India; faces; recurring; health; emergencies during heat waves, floods,; and pollution events -; heat stress,; dehydration, and cardiac; complications; outdoor workers, and rural; populations.; Healthcare access is often delayed; and connectivity.; 2024 was the warmest year on record in the country since 1901, and climate-related; disasters this problem is about.

spike, especially among elderly citizens,

exactly when disasters disrupt roads, power,

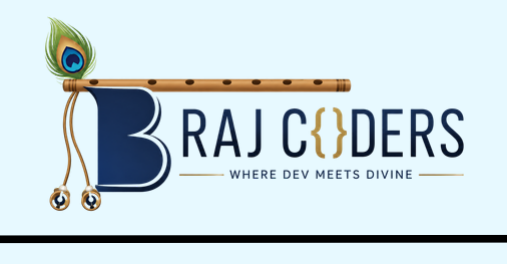
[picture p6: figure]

### In 2024, India experienced a significant rise in heatwave days, reaching 554 compared to

230 in 2023.

554 Days | 75% of India’s workforce, accounting for nearly 380 million people, is involved in outdoor and other heat-exposed occupations, making them particularly vulnerable to rising temperatures and extreme heat conditions.

50/100

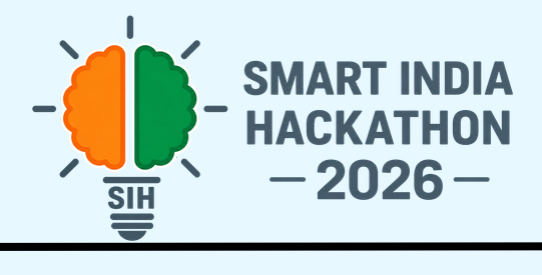
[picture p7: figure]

### rural internet penetration vs 127/100 in urban India the exact gap where cloud-dependent health apps fail rural India sits at just 48.31 per cent... Urban India, by contrast, stands at 126.80 per 100

population.

### hazards keep intensifying. Most wearable health tech assumes constant internet access the exact thing that breaks down during the

E

X

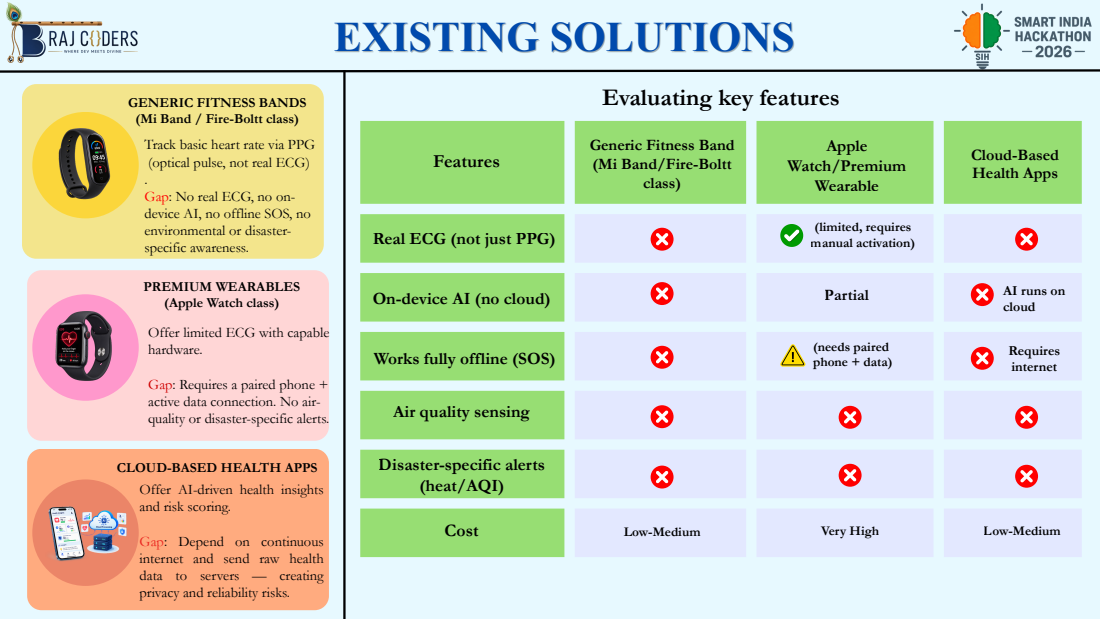
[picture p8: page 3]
Apple; ffl; Evaluating key features Features Cost; Low-Medium; internet; Cloud-Based Health Apps; g. Gap: Depend; e. Gap: Requ; tiv

GENERIC FITNESS BANDS
(Mi Band / Fire-Boltt class)
CLOUD-BASED HEALTH APPS Track basic heart rate via PPG (optical pulse, not real ECG) .Gap: No real ECG, no on- device AI, no offline SOS, no environmental or disaster- specific awareness. Offer AI-driven health insight

Watch/Premium Wearable Generic Fitness B

PREMIUM WEARABLES
(Apple Watch class)
s. Offer limited ECG with c

AI runs on
cloud Requires

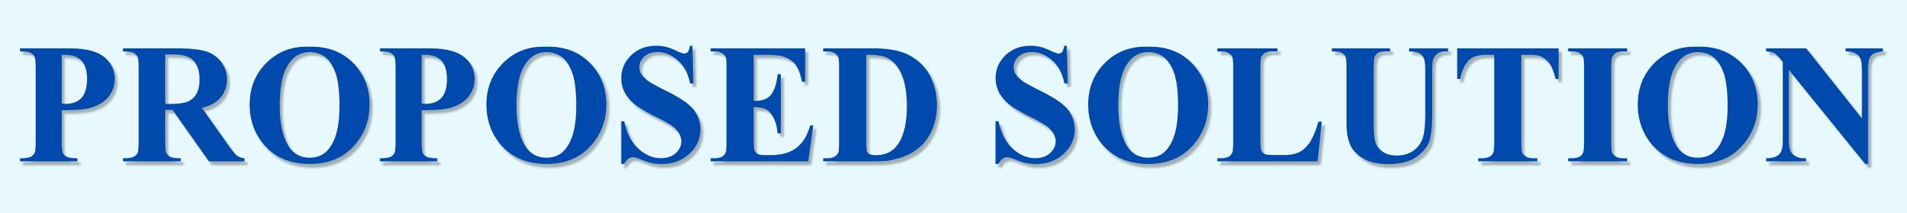
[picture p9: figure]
PROPOSED SOLUTION

“Develop a wearable that uses on-device AI to spot health risks early and stay useful during disasters." SIH26181 Sanjeevni reads your heartbeat, your movement, and the air around you, and warns you before things turn serious. All on your phone. Nothing sent to the cloud. Built for India's heat waves, floods, and pollution.

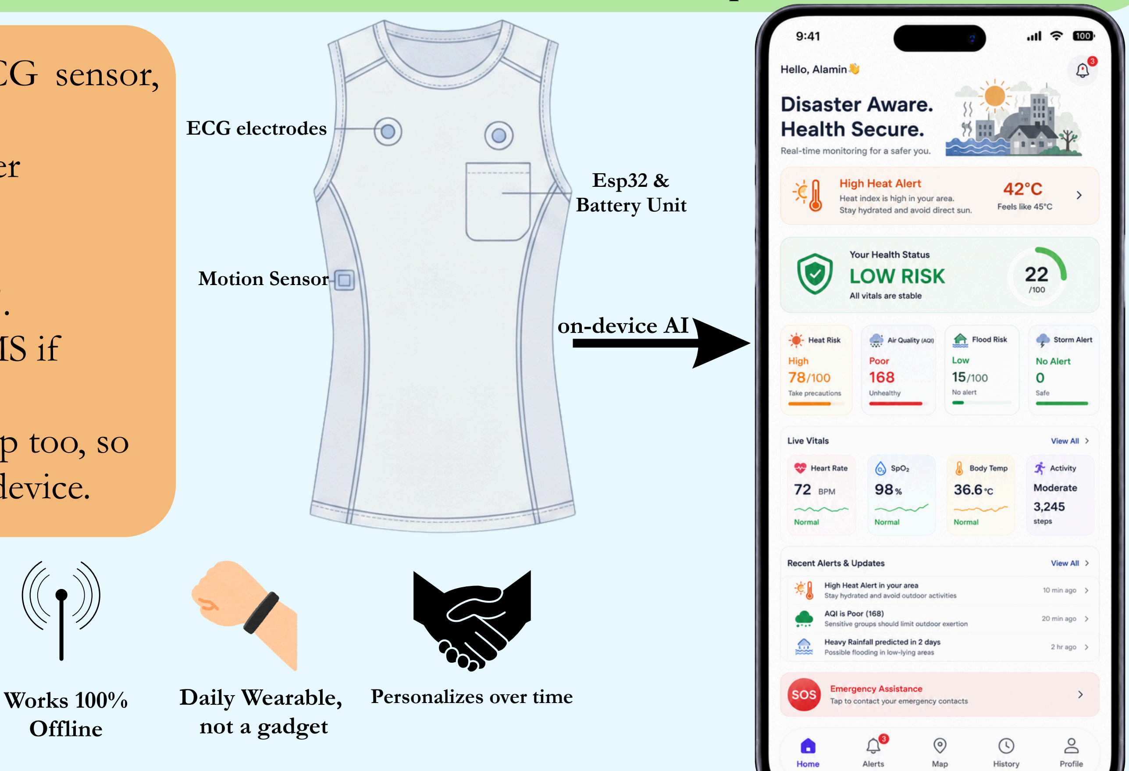
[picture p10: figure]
Motion Sensor; Esp32 & Battery Unit; ECG electrodes; Works 100% Offline; Daily Wearable,; not a gadget; Personalizes over time; on-device AI

Real heart signal, not guesswork: an actual ECG sensor,
not just a pulse count.

## Every alert is decided on your phone, not a server

somewhere.

## Knows the difference between "you

're just exercising" and "something's wrong".

## Still works with no internet: sends an SOS by SMS if

needed.

## Built into your clothing, tracks your rest and sleep too, so

you never have to remember to wear a separate device.

Real ECG hardware Runs on your phone, not the cloud Reads context,
not just numbers

# TECHNICALAPPROACH

### TIER 1 -SENSING LAYER

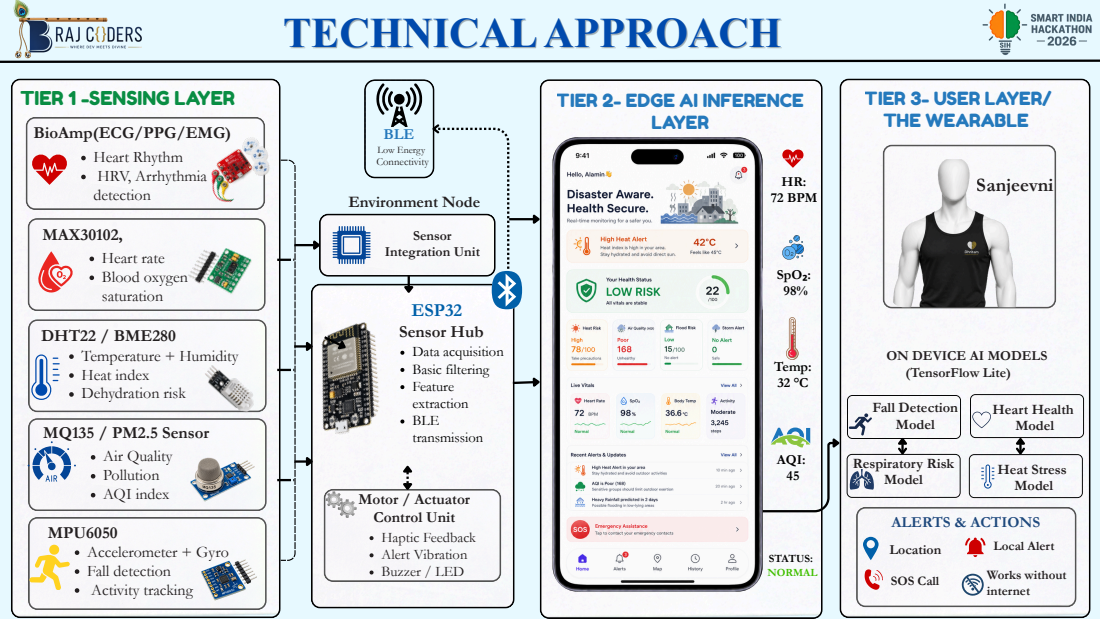
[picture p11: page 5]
SpO2 + PPG; MQ135 / PM2.5 Sensor; Temperature + Humidity Heat index Dehydration risk; Heart Rhythm HRV, Arrhythmia detection; Motor / Actuator Control Unit; Data acquisition Basic filtering Feature extraction BLE transmission; Sensor Integration Unit; Environment Node; ESP32 Sensor Hub; BLE; Low Energy Connectivity; Haptic Feedback Alert Vibration Buzzer / LED; Accelerometer + Gyro Fall detection Activity tracking; Air Quality Pollution AQI index; Heart rate Blood oxygen saturation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

Location TIER 3- USER LAYER/
THE WEARABLE

TIER 2- EDGE AI INFERENCE

BioAmp(ECG/PPG/EMG)

ON DEVICE AI MODELS
(TensorFlow Lite)

# SCALABILITY & SUSTAINABILITY

SCALABILITY | SUSTAINABILITY

Modular Hardware Design
Sensor modules (ECG, AQI, motion) can be added/removed independently, letting the product scale from a 3-sensor MVP to a full 5-sensor version without redesigning the core system

Low-Cost Manufacturing
Sub-₹2,500 unit cost enables mass | deployment
across population-scale use cases, | not just
premium/niche markets

Platform-Agnostic Software
On-device TFLite models run on any modern Android phone via NNAPI — no dependency on specific hardware, so the app scales across device tiers

Geographic Scalability
Fully offline operation means the product scales into rural and low-connectivity regions without needing new infrastructure

Low Power Design
Duty-cycled sampling and low-power BLE extend battery life, reducing charging
frequency | and | long-term | energy
consumption

Zero Recurring Cloud Cost
On-device inference means no per-user server/API cost — the business model stays financially sustainable even at large scale

Open-Source Stack
Built on React Native, TensorFlow Lite, ESP32 — avoids licensing lock-in, keeping long-term maintenance costs low

Reusable, Durable Hardware
Passive undergarment sensing (not disposable) supports long-term reuse rather than a consumable/replaceable product model

## TECHSTACK

React (Native) Tensorflow

Java script Android Studio

Python | BLE
Firebase | Arduino

SQLite

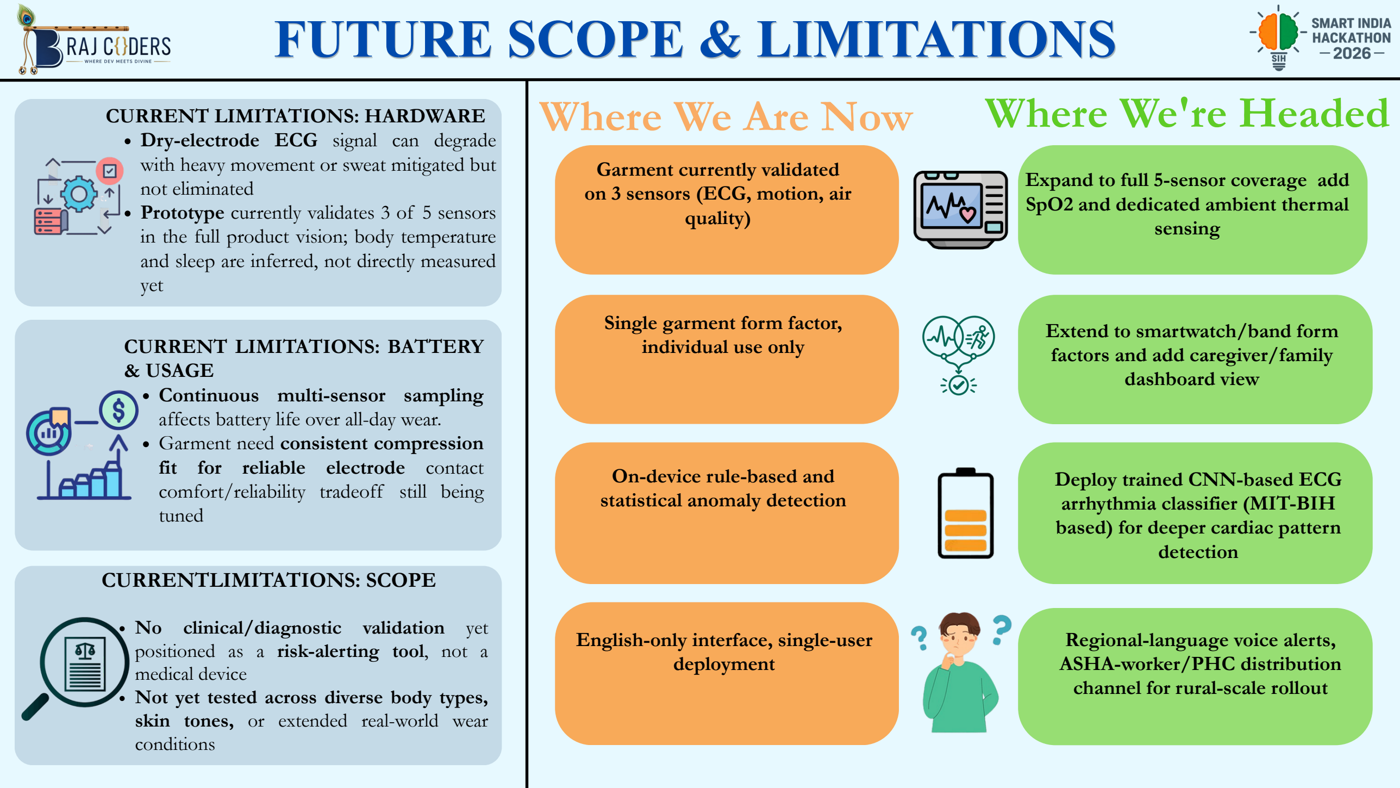
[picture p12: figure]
Where We're Headed; FUTURE SCOPE & LIMITATIONS; CURRENT LIMITATIONS: HARDWARE; Where We Are Now; Dry-electrode ECG signal can degrade; not eliminated; yet; CURRENT LIMITATIONS: BATTERY & USAGE Continuous multi-sensor sampling affects battery life over all-day wear. Garment need consistent compression fit for reliable electrode contact comfort/reliability tradeoff still being tuned; CURRENTLIMITATIONS: SCOPE; No clinical/diagnostic validation yet; medical device; skin tones, or extended real-world wear conditions; Single garment form factor, individual use only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

with heavy movement or sweat mitigated but

Prototype currently validates 3 of 5 sensors in the full product vision; body temperature and sleep are inferred, not directly measured

positioned as a risk-alerting tool, not a

Not yet tested across diverse body types,

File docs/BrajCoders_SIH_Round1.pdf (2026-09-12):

# SMART INDIA HACKATHON 2026

# SANJEEVNI

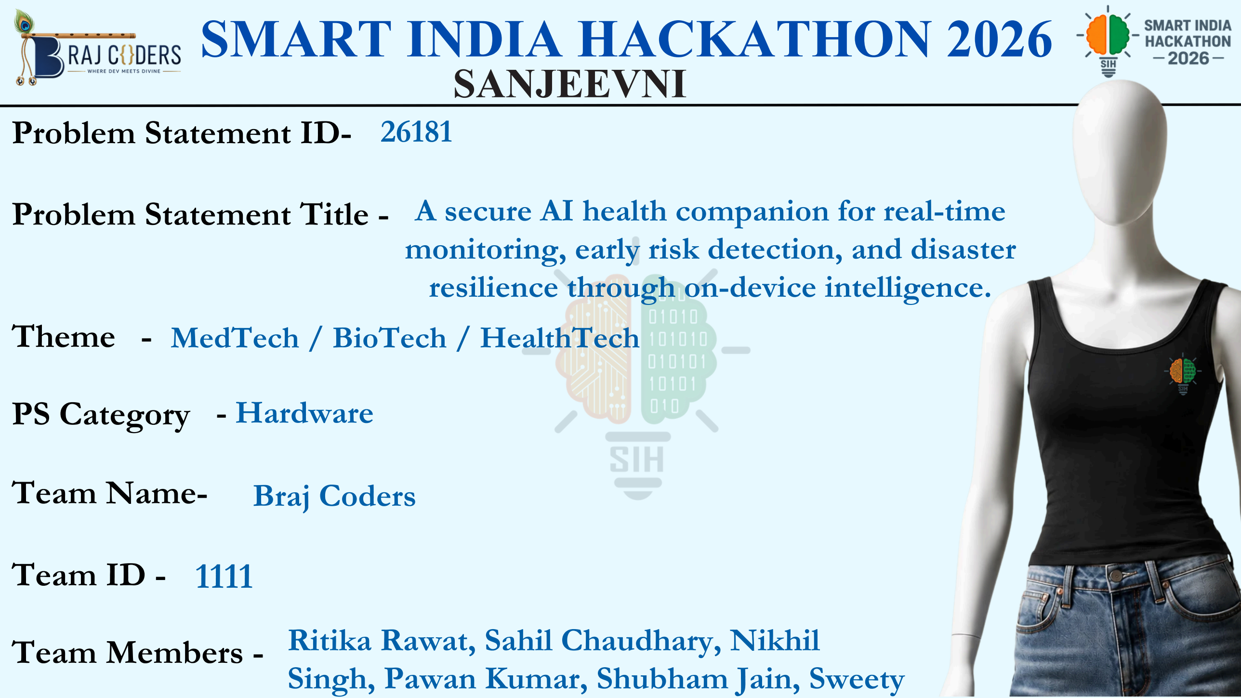
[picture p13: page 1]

# Theme

# Team ID -

# PS Category

# Team Name-

# Team Members -

# Problem Statement ID-

# Problem Statement Title -

# A secure AI health companion for real-time monitoring, early risk detection, and disaster

resilience through on-device intelligence.

# MedTech / BioTech / HealthTech

# - Hardware

# Braj Coders

26181

# Ritika Rawat, Sahil Chaudhary, Nikhil Singh, Pawan Kumar, Shubham Jain, Sweety

1111

“Develop a wearable that uses on-device AI to spot health risks early and stay useful during disasters." SIH26181 Sanjeevni reads your heartbeat, your movement, and the air around you, and warns you before things turn serious. All on your phone. Nothing sent to the cloud. Built for India's heat waves, floods, and pollution.

# AI-POWERED HEALTH & DISASTER RESILIENCE ECOSYSTEM

On-Device Intelligence Real-Time Protection.

Real heart signal, not guesswork: an actual ECG sensor, not just a pulse count.

## Every alert is decided on your phone, not a server

somewhere.

## Knows the difference between "you

## 're just exercising" and

"something's wrong".

## Still works with no internet: sends an SOS by SMS if

needed.

## Built into your clothing tracks your rest and sleep too, so

you never have to remember to wear a separate device.

ECG electrodes

Motion Sensor

Esp32 &
Battery Unit

Real ECG hardware Runs on your phone, not the cloud Reads context,
not just numbers

Works with
zero signal

Daily Wearable,
not a gadget

on-device AI

Personalizes over time

# TECHNICAL APPROACH

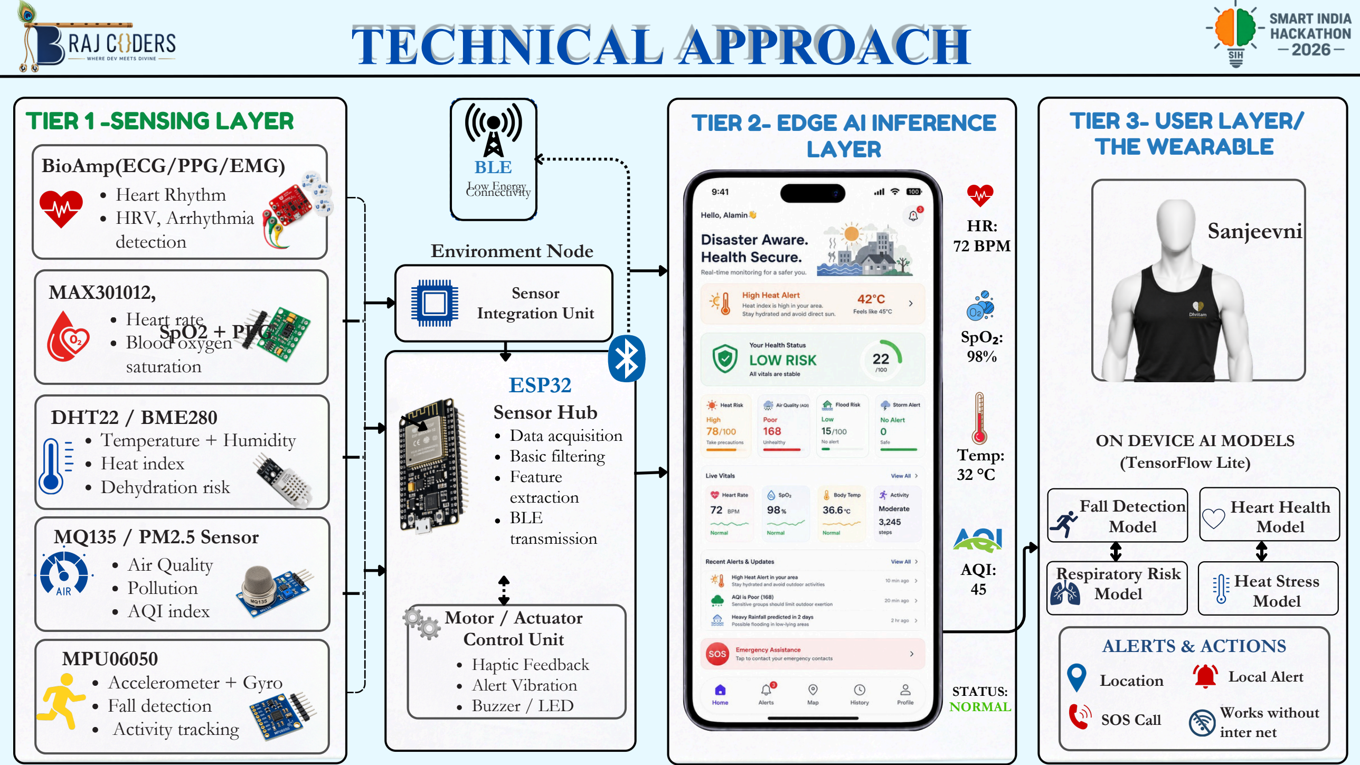
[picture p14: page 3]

MAX301012,

MPU06050

DHT22 / BME280

MQ135 / PM2.5 Sensor

SpO2 + PPG

BioAmp(ECG/PPG/EMG)

Sensor Hub

Air Quality
Pollution
AQI index

Heart rate
Blood oxygen
saturation

Heart Rhythm
HRV, Arrhythmia
detection

Accelerometer + Gyro
Fall detection
Activity tracking

Temperature + Humidity
Heat index
Dehydration risk

Environment Node

BLE

Motor / Actuator
Control Unit | ALERTS & ACTIONS
Haptic Feedback
Alert Vibration
Buzzer / LED

Data acquisition
Basic filtering
Feature
extraction
BLE
transmission

Sensor
Integration Unit

AQI:
45

HR:

### 72 BPM

SpO₂:
98%

Temp:
32 °C

Location

ON DEVICE AI MODELS
(TensorFlow Lite)

ESP32

Low Energy Connectivity

Fall Detection
Model

Respiratory Risk
Model

Heat Stress
Model

Heart Health
Model
TIER 1 -SENSING LAYER | TIER 2- EDGE AI INFERENCE LAYER

### TIER 3- USER LAYER/ THE WEARABLE

SOS Call

Local Alert

Works without
inter net

### Sanjeevni

STATUS:
NORMAL

Challenges | Solutions

# FEASIBILITY AND VIABILITY

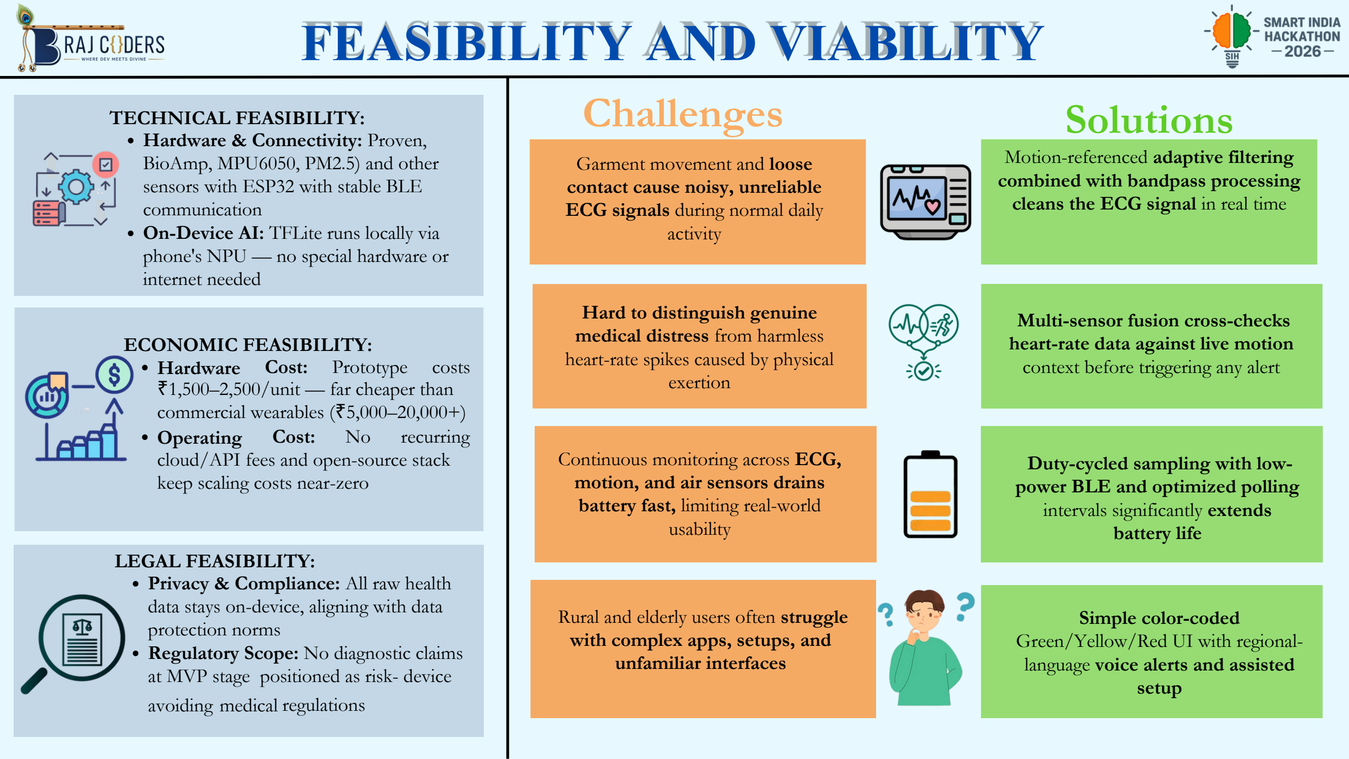
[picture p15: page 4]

Motion-referenced adaptive filtering combined with bandpass processing cleans the ECG signal in real time

ECONOMIC FEASIBILITY:
Hardware Cost: Prototype costs ₹1,500–2,500/unit — far cheaper than commercial wearables (₹5,000–20,000+)
Operating | Cost: | No | recurring
cloud/API fees and open-source stack keep scaling costs near-zero

LEGAL FEASIBILITY:
Privacy & Compliance: All raw health data stays on-device, aligning with data protection norms
Regulatory Scope: No diagnostic claims at MVP stage positioned as risk- device avoiding medical regulations

TECHNICAL FEASIBILITY:
Hardware & Connectivity: Proven, BioAmp, MPU6050, PM2.5) and other sensors with ESP32 with stable BLE communication
On-Device AI: TFLite runs locally via phone's NPU — no special hardware or internet needed

Garment movement and loose contact cause noisy, unreliable ECG signals during normal daily activity

Hard to distinguish genuine medical distress from harmless heart-rate spikes caused by physical exertion

Rural and elderly users often struggle with complex apps, setups, and unfamiliar interfaces

Continuous monitoring across ECG, motion, and air sensors drains battery fast, limiting real-world usability

Multi-sensor fusion cross-checks heart-rate data against live motion context before triggering any alert

Duty-cycled sampling with lowpower BLE and optimized polling intervals significantly extends battery life

Simple color-coded
Green/Yellow/Red UI with regionallanguage voice alerts and assisted setup

## IMPACTS

# IMPACT AND BENEFITS

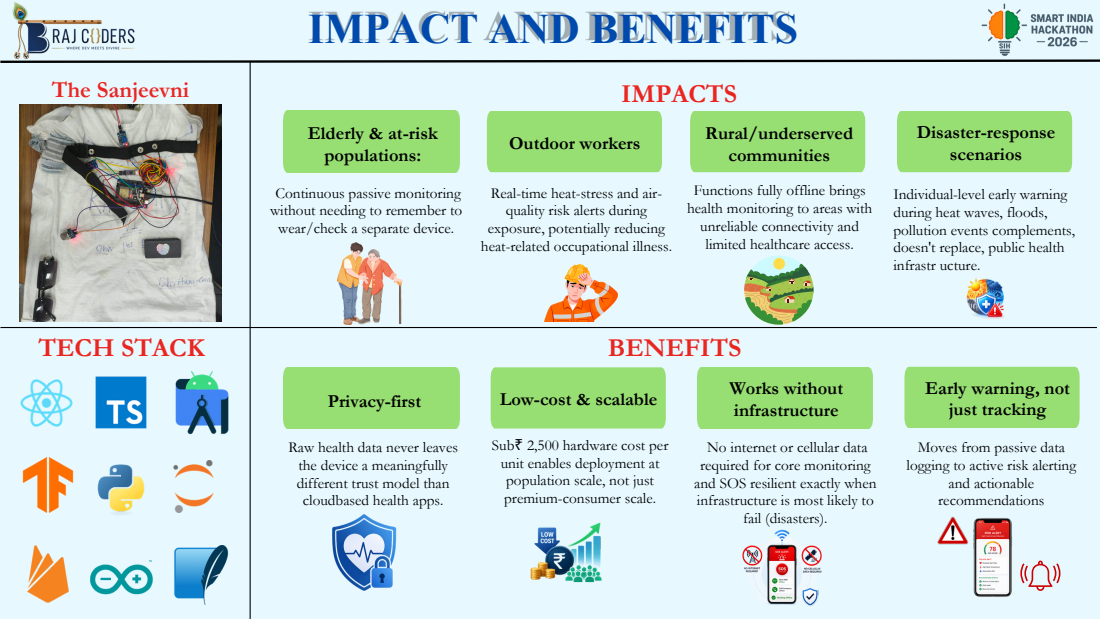
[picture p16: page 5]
TECH STACK; BENEFITS; Privacy-first; Outdoor workers; Low-cost & scalable; Works without; infrastructure; Rural/underserved communities; Disaster-response scenarios; The Sanjeevni

Elderly & at-risk
populations:

Continuous passive monitoring
without needing to remember to
wear/check a separate device.

Real-time heat-stress and air-
quality risk alerts during
exposure, potentially reducing
heat-related occupational illness.

Functions fully offline brings
health monitoring to areas with
unreliable connectivity and
limited healthcare access.

Individual-level early warning
during heat waves, floods,
pollution events complements,
doesn't replace, public health
infrastr ucture.

Early warning, not
just tracking

Sub₹ 2,500 hardware cost per
unit enables deployment at
population scale, not just
premium-consumer scale.

Raw health data never leaves
the device a meaningfully
different trust model than
cloudbased health apps.

No internet or cellular data
required for core monitoring
and SOS resilient exactly when
infrastructure is most likely to
fail (disasters).

Moves from passive data
logging to active risk alerting
and actionable
recommendations

# RESEARCH AND REFERENCES

## Evaluating key features

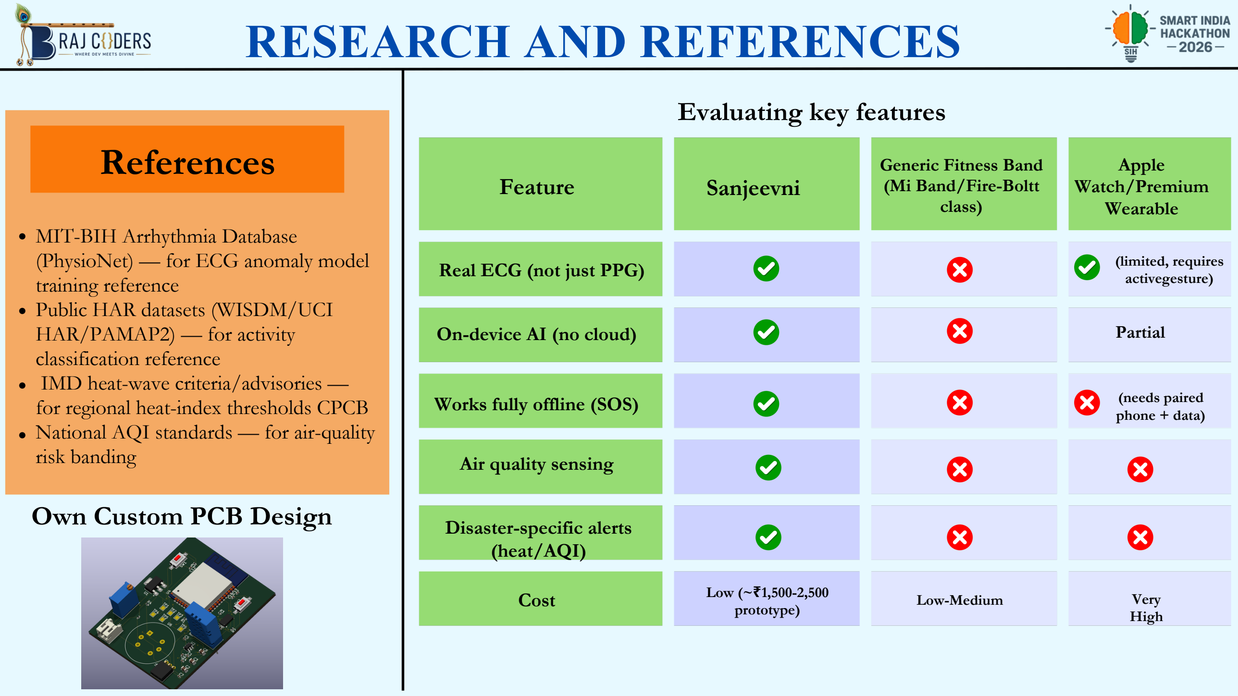
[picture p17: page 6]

Feature | Sanjeevni

Apple
Watch/Premium
Wearable

Generic Fitness Band
(Mi Band/Fire-Boltt
class)

Partial

Cost

Air quality sensing

Disaster-specific alerts
(heat/AQI)

On-device AI (no cloud)

Works fully offline (SOS)

Real ECG (not just PPG)

Low (~₹1,500-2,500
prototype)
Low-Medium | Very High

(needs paired
phone + data)

(limited, requires
activegesture)

MIT-BIH Arrhythmia Database (PhysioNet) — for ECG anomaly model training reference
Public HAR datasets (WISDM/UCI HAR/PAMAP2) — for activity classification reference
IMD heat-wave criteria/advisories — for regional heat-index thresholds CPCB National AQI standards — for air-quality risk banding

# References

## Own Custom PCB Design

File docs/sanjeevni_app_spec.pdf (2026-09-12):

Sanjeevni — App Feature & Design Specification | SIH 2026 — Team BrajCoders

# SANJEEVNI

## App Feature & UI/UX Design Specification

A Secure, AI-Powered Personal Health Companion for Disaster Resilience

Smart India Hackathon 2026 | — Problem Statement 26181 | — Team BrajCoders (Team ID 1111)

Purpose of this document. This is a two-part specification. Part I lists and prioritizes every feature the app will have, using the 80/20 principle: which 20% of features deliver 80% of the perceived value to a mentor, a judge, and – most importantly – a real Indian user in a heat wave, flood, or pollution event. Part II is the developer-facing design document: for every feature, what to build, how it should look and behave (UI/UX), and why it is designed that way for the Indian context specifically. Anyone on the team should be able to read Part I alone and explain the entire app to a judge.

## Contents

1 Design Philosophy – Read This Before Anything Else | 2
2 Part I — Complete Feature List (Prioritized, 80/20 Principle) | 2
3 Codebase Folder Structure (Reference) | 5
4 Part II — Developer Design Document (Screen by Screen) | 6
5 Summary: What to Build First (Team Priority Order) | 11

## 1 Design Philosophy – Read This Before Anything Else

A dashboard that mirrors sensor values (“HR: 72, SpO2: 98%, Temp: 32 deg C”) is not a product – it is a science-fair demo. The product is the layer of judgment sitting on top of the numbers. Every screen in Sanjeevni must answer exactly one of three questions for the person looking at it:

1. “Am I okay right now?” – status, in plain language, not a number.
2. “What should I do about it?” – one clear, small, doable action.
3. “Who else needs to know?” – escalation to family, caregiver, or emergency services.

The Indian-context constraints that shape every decision in this document:

Rural internet penetration is 48.31 per 100 vs. 126.80 per 100 in urban India – the app must be fully useful with zero or intermittent connectivity, not just “work offline as a fallback.”

The primary at-risk users – elderly citizens and outdoor laborers – are frequently not the most digitally literate members of their household. A family member is often the one who will actually monitor the app.

Health literacy varies widely; numbers (SpO2 94%, heat index 41 deg C) mean very little to most users without translation into an action.

Multiple Indian languages, and in many cases low reading literacy even in one’s own language, means voice and icons must be first-class, not accessibility add-ons.

Trust in unfamiliar health-tech is reasonably low; the app must be transparent about what it is (a risk-alerting companion) and is not (a diagnostic medical device).

The real distribution and adoption path is institutional (ASHA workers, Primary Health Centres, disaster-response agencies, employers of outdoor labor) as much as individual consumers – the app must serve both a single wearer and someone monitoring many people at once.

## 2 Part I — Complete Feature List (Prioritized, 80/20 Principle)

This section is written so that any team member can read it top to bottom and be able to explain the entire app to a mentor or judge in five minutes, without touching code. Every feature is tagged by build priority, following the same scheme as the team’s build guide:

[P1 – CORE DEMO FEATURE] The demo does not work without this – build first
[P2 – HIGH VALUE] | Makes the demo genuinely convincing and matches judging rubric directly
[P3 – IF TIME PERMITS] | Build only after all P1/P2 are done across the whole team

### 2.1 PS Requirement 1: Continuous Health Monitoring

[P1 – CORE DEMO FEATURE] Live Vitals screen: heart rate, HRV-derived stress cue, motion state, environment context – shown as status, not a raw table.

[P1 – CORE DEMO FEATURE] Personal baseline learning (rolling per-user average of resting HR, RR-variance, heat tolerance) – “normal for you,” not a textbook number.

| [P2 – HIGH VALUE] Daily wellness summary card (“Today was a normal day”).
| [P3 – IF TIME PERMITS] Sleep quality (inferred from night-time motion + HR patterns,
since no dedicated sleep sensor exists yet).

### 2.2 PS Requirement 2: AI-Based Health Anomaly Detection

| [P1 – CORE DEMO FEATURE] Real-time cardiac risk flag (rhythm-anomaly z-score vs. personal baseline, gated by signal quality and motion).
| [P1 – CORE DEMO FEATURE] Confidence-aware risk levels (NORMAL / CAUTION / RISK) – never a false sense of precision.
| [P2 – HIGH VALUE] “Why am I seeing this?” evidence trail in plain language (translates your engine’s internal evidence[] array into a human sentence).
| [P3 – IF TIME PERMITS] Trend-based early warning (predicting a rise 15–30 minutes ahead, not just flagging the present).

### 2.3 PS Requirement 3: Disaster-Specific Health Alerts

| [P1 – CORE DEMO FEATURE] Heat-Wave Mode: heat-index-based warning + a person- alized “safe hours to work outside today” plan.
| [P2 – HIGH VALUE] Air-Quality Mode: AQI-based respiratory-risk alert + best/worst hours for outdoor exposure.
| [P2 – HIGH VALUE] Flood/Cyclone Advisory: pulled from public IMD/NDMA feeds for the user’s district, paired with a personal note for vulnerable users.
| [P1 – CORE DEMO FEATURE] Every alert type ships with a matching “What to do” action card (symptoms to watch, immediate first steps) – cheap to build, highest value-per-effort feature in the whole app.

### 2.4 PS Requirement 4: Environmental Awareness

| [P1 – CORE DEMO FEATURE] Live environment strip (temperature, humidity, AQI) with source shown (garment sensor vs. public API) – builds trust by being honest about data provenance.
| [P2 – HIGH VALUE] Personalized environmental recommendation engine (same AQI reading gives different advice to a healthy adult vs. a vulnerable user).

### 2.5 PS Requirement 5: Privacy-Preserving Edge AI

| [P1 – CORE DEMO FEATURE] Persistent, always-visible “On-Device” / “Nothing leaves your phone” trust indicator.
| [P1 – CORE DEMO FEATURE] Plain-language “How this works” screen (what the app does and explicitly does not do).
| [P2 – HIGH VALUE] Data-sharing control panel (what, if anything, syncs to a caregiver or PHC dashboard, and an explicit opt-in toggle).

### 2.6 PS Requirement 6: Emergency Assistance Features

| [P1 – CORE DEMO FEATURE] One-tap, always-reachable SOS button with visible count- down (cancellable) before auto-send.
| [P1 – CORE DEMO FEATURE] Automatic fall/distress detection triggering the same SOS flow.
| [P1 – CORE DEMO FEATURE] SMS-based SOS (works with zero data connectivity) with a pre-drafted, informative message and last-known location.

[P2 – HIGH VALUE] Caregiver/Family Companion View – read-only linked account for a family member, who also receives RISK-level alerts directly.

### 2.7 PS Requirement 7: Personal Wellness Dashboard

| [P1 – CORE DEMO FEATURE] Traffic-light home screen status (green/yellow/red) as the single headline element.
| [P2 – HIGH VALUE] Category risk scores (cardiac / heat / respiratory / fall) shown as simple gauges, each with one-line plain-language explanation.
| [P2 – HIGH VALUE] Weekly trend summary in plain language, not a raw graph.
| [P3 – IF TIME PERMITS] Full historical trend graphs for power users / clinicians.

### 2.8 PS Requirement 8: Scalable Deployment

| [P2 – HIGH VALUE] ASHA Worker / PHC Companion Mode: a single list view of everyone in a health worker’s care area, sorted by risk level.
| [P3 – IF TIME PERMITS] Multi-device abstraction layer (band/smartwatch form factor support without redesigning the app).

### 2.9 Cross-Cutting Features (apply to the whole app, not one PS bullet)

| [P1 – CORE DEMO FEATURE] Voice-first regional language support – spoken alerts, not just translated text; single highest-leverage feature for elderly and low-literacy users.
| [P1 – CORE DEMO FEATURE] Icon-first, low-literacy-friendly onboarding – tap-a- picture vulnerability profile instead of a medical form.
| [P2 – HIGH VALUE] Visible “Working Offline” badge – reinforces the core disaster- resilience promise every time the app is opened.
| [P3 – IF TIME PERMITS] Accessibility pass (large-text mode, high-contrast mode) for elderly users with vision difficulty.
| The 20% that delivers 80% of the value, if the team must cut scope: traffic-light home screen + plain-language “what to do” alert cards + one-tap SOS with SMS fallback + voice alerts in a regional language + the caregiver view. These five features alone turn Sanjeevni from “a wearable that shows numbers” into “a health companion that protects a family,” which is the entire pitch.

## 3 Codebase Folder Structure (Reference)

sanjeevni/
|-- ai-engine/ | (Phase-1 DSP + statistics engine -- DONE)
| | |-- ecg/ | filters, R-peak, HRV, rhythm anomaly, SQI
| | |-- environment/ | heat index, AQI source, respiratory risk
| | |-- motion/ | activity state, fall detection
| | |-- fusion/ | multi-sensor fusion
| | |-- decision/ | false-alarm gate, risk decision engine
| | |-- baseline/ | personal baseline learning
| | ‘-- index.ts | processSensorTick() orchestrator
|-- esp32-firmware/
| | ‘-- sanjeevni_firmware.ino | sensor acquisition + BLE/serial packetizing
|-- server/
| | ‘-- src/
| | |-- serialBridge.ts | serial parsing, packet -> SensorTickInput
| | ‘-- server.ts | HTTP + WebSocket broadcast to frontend
‘-- app/ | <-- THIS DOCUMENT DESIGNS THIS LAYER
|-- src/
| | |-- screens/
| | | | |-- OnboardingFlow/ | (Sec. 4.1)
| | | | |-- HomeStatus/ | (Sec. 4.2)
| | | | |-- DisasterModes/ | (Sec. 4.3)
| | | | |-- EmergencySOS/ | (Sec. 4.4)
| | | | |-- WellnessDashboard/ | (Sec. 4.5)
| | | | |-- CaregiverView/ | (Sec. 4.6)
| | | | |-- TrustAndPrivacy/ | (Sec. 4.7)
| | | | ‘-- AshaWorkerMode/ | (Sec. 4.8)
| | |-- components/
| | | | |-- StatusOrb.tsx | traffic-light home indicator
| | | | |-- ActionCard.tsx | "what to do" card, reused everywhere
| | | | |-- RiskGauge.tsx | category risk score gauge
| | | | |-- VoiceAlertPlayer.tsx | TTS playback for regional language
| | | | |-- OfflineBadge.tsx | connectivity state indicator
| | | | ‘-- SOSButton.tsx | global emergency trigger
| | |-- i18n/ | regional language strings + TTS assets
| | |-- services/
| | | | |-- websocketClient.ts | connects to server.ts /ws
| | | | |-- smsService.ts | native SMS SOS dispatch
| | | | ‘-- localStorage.ts | SQLite -- readings, alerts, profile
| | ‘-- state/ | app-wide status/risk state store
‘-- assets/
|-- icons/ | vulnerability-profile picture set
‘-- voice/ | pre-recorded regional-language phrases

## 4 Part II — Developer Design Document (Screen by Screen)

### 4.1 Onboarding Flow

[P1 – CORE DEMO FEATURE]

What it is. The very first experience – must work for a first-time smartphone user with no assumed literacy.

UI/UX specification.

| Screen speaks its own instructions aloud on load, in the language selected on the very first tap (large flags/scripts, not a dropdown list).
| Vulnerability profile step: a grid of 6–8 large icon cards (elderly person, outdoor worker, pregnant, heart condition, child, none-of-these) – user taps as many as apply. No text typing required at all for this step.
| Emergency contact step uses the native contact picker, never a manual phone-number text field – typing a phone number correctly on a small keyboard is a common failure point for elderly users.
| A single “Calibrating your normal...” screen with a simple animated progress ring while the app collects ˜60 seconds of resting baseline data – explained as “We’re learning what’s normal for your body,” never using the word “baseline” or any technical term in-app.

Why this design, for India specifically. Manual form-filling is the single biggest drop-off point for low-literacy and first-time smartphone users. Every step above replaces typing with tapping a picture or using a built-in phone capability (contacts) the user already understands from making calls.

### 4.2 Home / Status Screen

[P1 – CORE DEMO FEATURE]

What it is. The one screen a user should be able to glance at and understand in under three seconds – this is the screen a judge will remember.

UI/UX specification.

| Top of screen, largest element: a single colored orb/card (green / yellow / red) with one short sentence written the way a person would say it out loud:
| – Green: “You’re doing fine. Stay hydrated, it’s a hot afternoon.”
| – Yellow: “Your heart rate is a bit high for resting. Sit somewhere shaded for a few minutes.”
| – Red: “This doesn’t look normal. Please sit down and consider calling for help.”
| Below the status sentence, in smaller/secondary typography: the actual numbers (HR, SpO2, temperature, AQI) for users who want detail – numbers are secondary information, never the headline.
| A persistent, small “Working Offline” / “Connected” badge in the header – always visible, never hidden in settings.
| A persistent, small lock-icon “On-device – nothing leaves your phone” badge near the status card.
| The SOS button is always visible as a floating element on this screen, not nested in a menu.

Why this design. A traffic light plus one plain sentence is understandable to any literacy level, any language (before translation even happens, color + tone of voice already communicate urgency), and any age group. This single design decision is what separates Sanjeevni from a generic vitals-tracking app – it is stated first because it is the highest-leverage screen in the entire product.

### 4.3 Disaster-Specific Modes

[P1 – CORE DEMO FEATURE] (Heat Wave) [P2 – HIGH VALUE] (Air Quality, Flood/Cyclone)

What it is. Context-aware modes that activate automatically based on environmental thresholds, rather than the user having to seek them out.

UI/UX specification.

Auto-activating banner, not a menu item the user must find – when heat-index/AQI/public advisory thresholds are crossed, a banner appears at the top of the Home screen: “Heat Wave Alert Today.”

Tapping it opens a single-screen daily plan, not a wall of data: “Best hours to work outside today: before 10am, after 5pm.” This reframes a temperature number into a schedule – the single most actionable transformation for an outdoor worker.

Every disaster mode ships with a matching, ultra-short “What to do” Action Card: 3–4 bullet points maximum, large text, e.g., symptoms of heat stroke to watch for, what to drink, what to avoid, how to cool someone down while waiting for help.

Flood/Cyclone Advisory pulls public IMD/NDMA district-level alerts (via public API when online) and layers a one-line personal note for vulnerable-flagged users: “A flood alert is active in your area. If you have a chronic condition, keep your emergency contact informed of your location today.”

Why this design. This is the module that most directly answers the Problem Statement’s explicit call for “resilience during heat waves, floods, pollution events, and other disasters.” It is also the cheapest-to-build, highest-perceived-value feature in the entire app: it requires no new hardware, only good content design and threshold logic already available from heatIndex.ts and respiratoryRisk.ts.

### 4.4 Emergency SOS Flow

[P1 – CORE DEMO FEATURE]

What it is. The safety-critical path – must be designed for a person in genuine distress or panic, not a calm browsing session.

UI/UX specification.

One large, high-contrast button reachable from every screen in the app (floating action button, not buried in a tab).

On automatic fall/distress detection: a full-screen takeover with a large, visible, audible 10–15 second countdown and one giant “I’m OK, Cancel” button – directly reflects the engine’s own fall-detection state machine (FREEFALL -> IMPACT -> CONFIRMED), giving the human a chance to override a false positive before anything is sent.

SOS message is pre-drafted and informative, never just “Help”: “[Name] may need help. Possible [fall/heat stress] detected near [location] at [time]. Sent automatically by Sanjeevni.”

SMS is the primary delivery path, not a fallback – works on any phone, any network quality, with zero data connectivity, matching the app’s core offline-first promise.

Post-SOS screen shows delivery confirmation (“Message sent to Ramesh (son)”) so the user isn’t left wondering if it worked.

Why this design. Rural network reliability makes SMS – not app notifications or data-based messaging – the only dependable channel during an actual disaster, which is precisely when this feature matters most. The cancellable countdown is essential given the engine’s own honesty about false-positive risk in fall detection.

### 4.5 Personal Wellness Dashboard

[P2 – HIGH VALUE]

What it is. The screen for someone who wants more than the one-line status – trend and history, still in plain language.

UI/UX specification.

| Four simple gauges (cardiac / heat / respiratory / fall risk), each a simple dial from green to red, each with exactly one sentence underneath translating the engine’s evidence[] array into plain language (e.g., “Your heart rate has been a little higher than usual today, but nothing urgent.”).
| A daily card: “Today was a normal day. Your resting heart rate stayed close to your usual.” – gives the app a reason to be opened even on days nothing goes wrong, which matters for long-term retention/wear compliance.
| Weekly view in plain language sentences first, with an optional graph underneath for anyone who wants it – never lead with the graph.

Why this design. A pure-alert app that stays silent 95% of the time gets forgotten and eventually stops being worn. A short, positive daily summary builds a habit loop and keeps the device on the body – which is the actual precondition for all the safety features to work at all.

### 4.6 Caregiver / Family Companion View

[P2 – HIGH VALUE]

What it is. A linked, simplified view for a family member – often the one who is more digitally engaged than the wearer.

UI/UX specification.

| Read-only mirrored version of the Home Status screen for the linked person, plus a small list if monitoring more than one family member (e.g., both parents).
| Direct push notification to the caregiver on any RISK-level alert – in addition to, not instead of, notifying the wearer.
| Simple “Last seen active” / “Last check-in” timestamp, so a distant family member has a lightweight way to know their parent is okay without needing a phone call every day.

Why this design. Elderly users are frequently not the ones who will check a phone app daily – a child or relative, possibly in a city with better connectivity, will. Routing critical alerts to whoever is most likely to act on them, not just the wearer, is what actually turns a detected risk into a real-world intervention. This is also a genuine differentiator no competitor in the comparison table offers.

### 4.7 Trust & Privacy Screen

[P1 – CORE DEMO FEATURE]

What it is. A plain-language explanation of what the app is and is not – necessary given reasonable public wariness of unfamiliar health-tech.

UI/UX specification.

| One screen, plain language, no jargon: “This device does NOT diagnose disease. It watches for early warning signs and tells you when something looks unusual for your body.”
| A persistent, small badge visible from the Home screen (not just buried in this settings-like screen) reiterating “Nothing leaves your phone.”
| A simple data-sharing control: toggle for whether anything syncs to a caregiver or, in institutional deployments, a PHC/ASHA worker dashboard – explicit opt-in, never default-on.

Why this design. Builds real trust rather than assuming users will read a privacy policy (they won’t). Also protects the product from over-reliance/misuse claims by being explicit about its non-diagnostic scope directly in the product, not just in the pitch deck.

### 4.8 ASHA Worker / PHC Companion Mode

[P2 – HIGH VALUE]

What it is. A separate, simple mode for a health worker monitoring many people at once – this is the feature that turns Sanjeevni from a single-user gadget into public health infrastructure.

UI/UX specification.

| A single list view of everyone in the worker’s care area, sorted by risk level (red first), each row showing name, one-line status, and last-updated time.
| Tapping a person opens their simplified Home Status view (read-only) – no need to learn a second interface.
| Designed for quick daily scanning on a basic Android phone, not a data-dense clinical dashboard.

Why this design. This directly matches the actual go-to-market and distribution path identified for reaching rural populations at scale (ASHA/PHC networks), and lets one health worker efficiently prioritize which households to visit first during a heat wave or flood – a capability no competitor product offers, and one that directly strengthens the Innovation and Potential Impact scoring criteria.
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

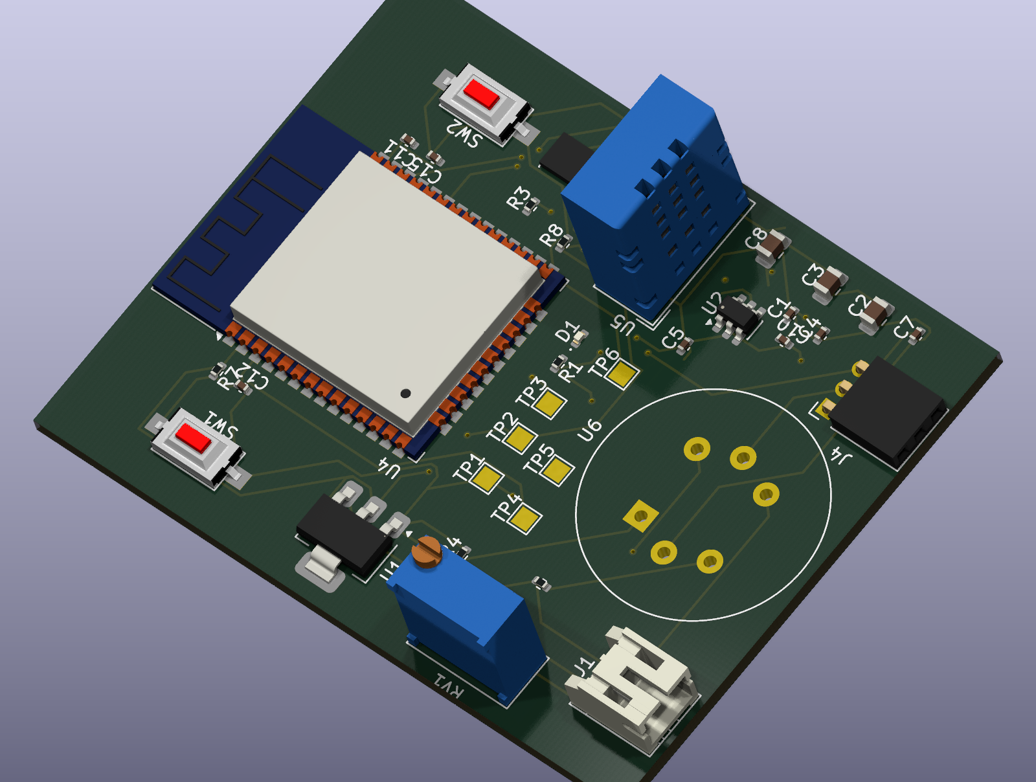
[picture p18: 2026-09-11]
Hardware/Sanjeevni_PCB/images/isometric_view_1.png

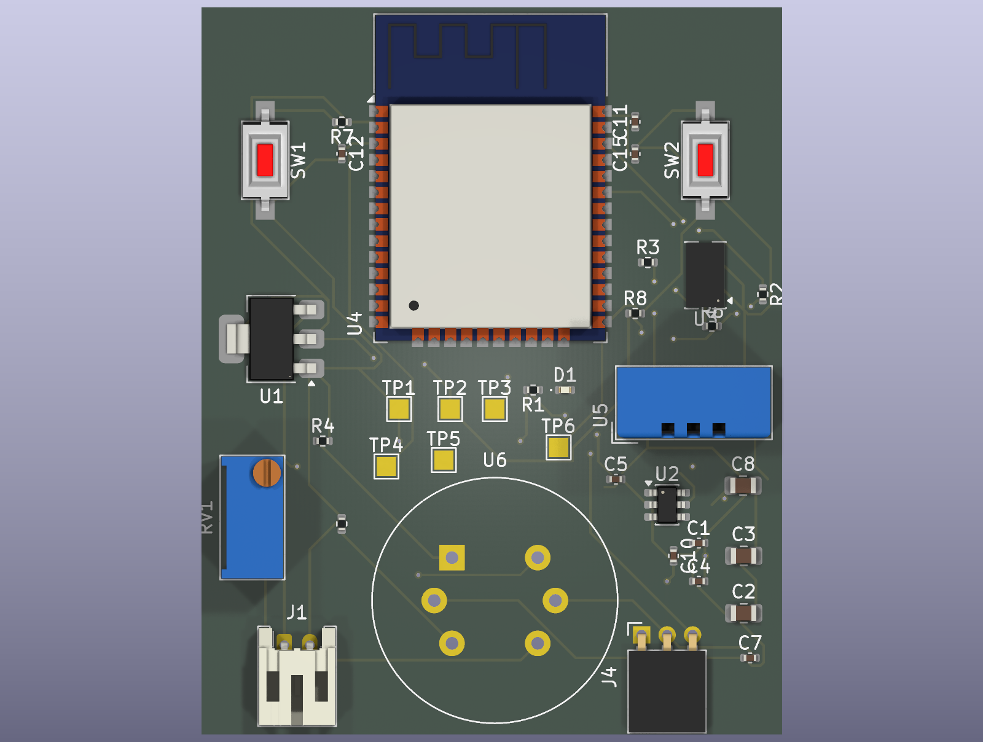
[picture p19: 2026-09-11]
Hardware/Sanjeevni_PCB/images/top_view.png

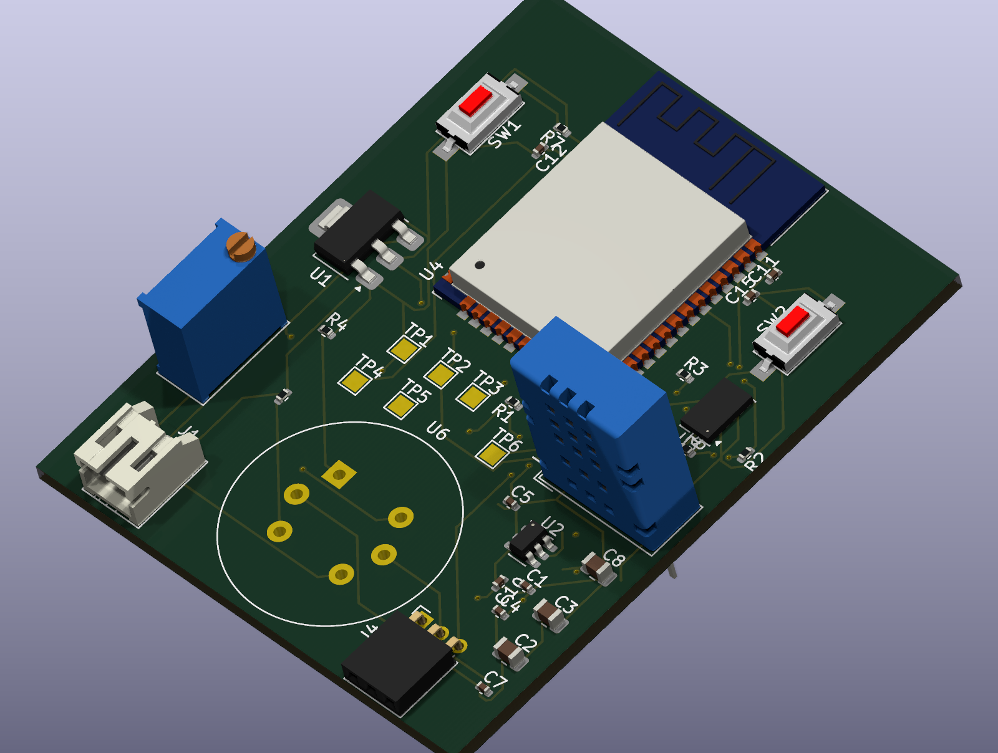
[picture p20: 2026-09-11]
Hardware/Sanjeevni_PCB/images/isometric_view_2.png

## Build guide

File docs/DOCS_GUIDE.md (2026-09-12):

# Project Documentation & Specifications

This directory contains reference documents, technical specifications, hardware build guides, and presentation decks created for the Sanjeevni project.

---

## Document Index

| Document | Format | Description |
| :--- | :--- | :--- |
| [`sanjeevni_app_spec.pdf`](sanjeevni_app_spec.pdf) | Technical Specification | Functional and architectural specification of the Sanjeevni mobile companion application. Details UI state machines, offline-first data flows, BLE protocol contracts, on-device AI integration, and local SQLite persistence. |
| [`sanjeevni_buildguide.pdf`](sanjeevni_buildguide.pdf) | Hardware Build Guide | Step-by-step assembly instructions for breadboard prototyping and custom hardware integration. Covers ESP32 wiring, pinouts, passive filtering components, sensor breakout modules, and power supply considerations. |
| [`BrajCoder's_SIH_Round1.pdf`](BrajCoder's_SIH_Round1.pdf) | Presentation Deck | Smart India Hackathon Round 1 presentation covering the initial problem statement, target demographics (industrial workers, miners, athletes), technical approach, and system block diagrams. |
| [`BrajCoders_SIH_Round1.pdf`](BrajCoders_SIH_Round1.pdf) | Presentation Deck | Smart India Hackathon Round 1 presentation covering the initial problem statement, target demographics (industrial workers, miners, athletes), technical approach, and system block diagrams. |
| [`BrajCoders_SIH_2026.pdf`](BrajCoders_SIH_2026.pdf) | Presentation Deck | Comprehensive hackathon project submission detailing the working hardware prototype, on-device DSP algorithms (Pan-Tompkins, Biquad IIR, Rothfusz heat index), custom PCB design, test results, and field deployment feasibility. |

---

## Technical Highlights by Document

### 1. Application Specification (`sanjeevni_app_spec.pdf`)
- **Offline Requirements**: Defines the design criteria for 100% offline operation without internet connectivity, remote APIs, or cloud infrastructure.
- **Biomedical Signal Pipeline**: Outlines the 500 Hz biopotential ingestion from the BioAmp EXG Pill, continuous windowing, Pan-Tompkins QRS detection, and heart rate variability (HRV) metrics.
- **Environmental Hazard Fusion**: Specifies the multi-sensor correlation model combining ambient temperature, relative humidity, and air quality (MQ135 ADC readings).
- **Storage & Retention**: Details the on-device SQLite database schema, indexing strategies, and automated 7-day circular pruning policy.

### 2. Hardware Build Guide (`sanjeevni_buildguide.pdf`)
- **Bill of Materials**: Component lists for both benchtop breadboard validation and prototype hardware assembly.
- **Wiring & Pin Allocation**: Complete pin mapping for ESP32 DevKit V1 interfacing with BioAmp EXG, ADXL345 (I2C), DHT11, MQ135, and capacitive moisture sensors.
- **Power Budget & Regulation**: Details 3.7V LiPo battery operation, AMS1117 3.3V linear regulation for the microcontroller and sensitive analog front-ends, and 5V step-up boost conversion for the MQ135 heater element.
- **Assembly Verification**: Verification checkpoints for power rail voltages, I2C pull-ups, analog reference noise, and serial debug telemetry.

### 3. Presentation Decks
- **Context**: Developed for evaluation in the Smart India Hackathon (SIH) under Team BrajCoders.
- **Scope**: Explains the rationale behind moving biomedical intelligence from the cloud to the extreme edge (the user's phone paired with a wearable ESP32 hub). Focuses on emergency response in underground mining, outdoor industrial plants, high-altitude sports, and remote patient monitoring.

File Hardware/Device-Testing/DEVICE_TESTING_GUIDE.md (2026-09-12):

# Sanjeevni Hardware Device Testing & Verification Guide

> **Project:** SIH GLAH10 — BrajCoders  
> **Subsystem:** Wearable Sensor Hub Hardware Testing (`Hardware/Device-Testing/`)  
> **Target Hardware:** ESP32 (DevKit V1 / WROOM-32D), BioAmp EXG Pill, ADXL345, DHT11, MQ135, Conductive Sweat Electrode  
> **Mobile App Target:** Sanjeevni Mobile Telemetry & Edge AI App  

---

## 1. Overview & Test Architecture

Before deploying the unified **`ESP32_Sensor_Hub.ino`** firmware, every hardware sensor and communication interface was subjected to isolated component testing. This modular testing strategy guarantees that electrical shorts, bus contention, timing jitter, or sensor miswiring are discovered and resolved in isolation.

Device testing is organized into two distinct verification tiers:

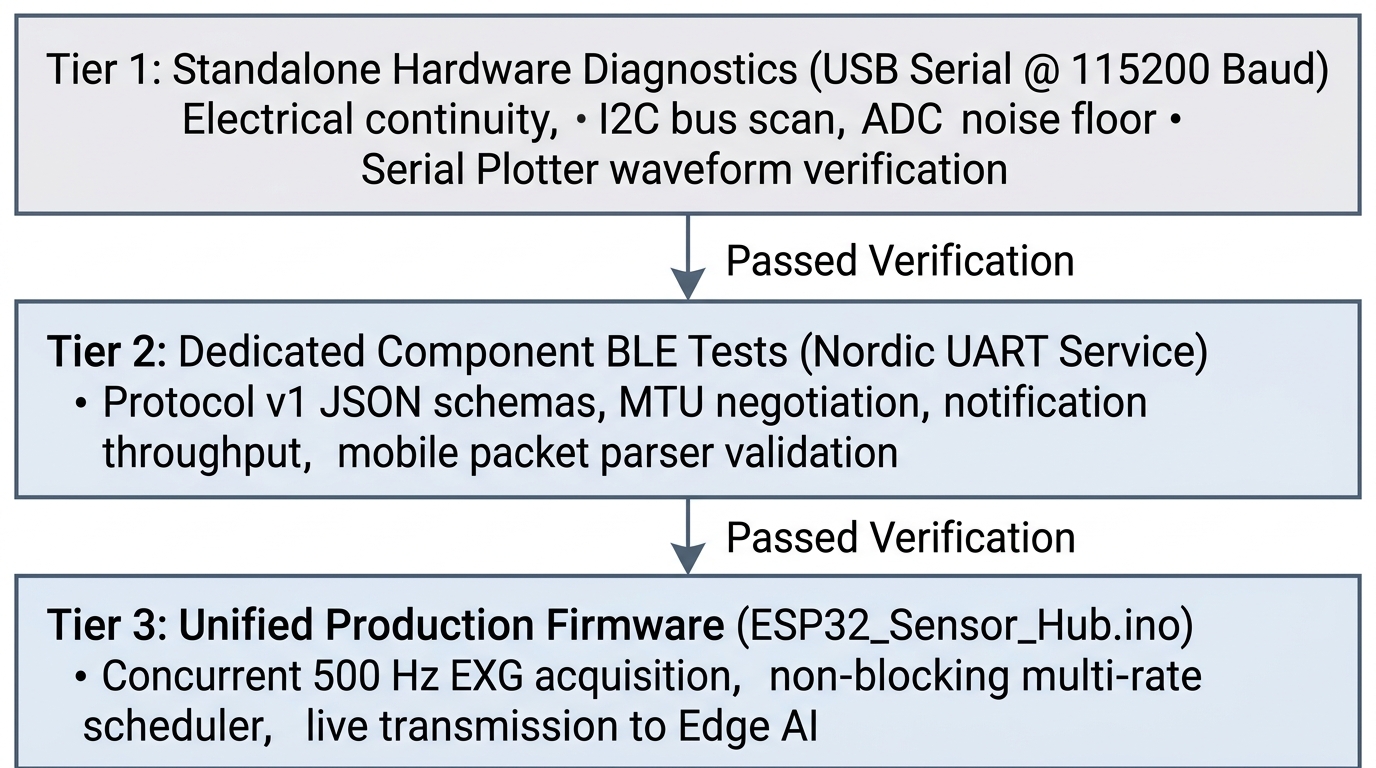
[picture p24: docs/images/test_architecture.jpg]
Multi-Tier Verification Architecture


---

## 2. Directory Structure & Sketch Inventory

The `Device-Testing/` directory contains standalone diagnostic sketches and individual BLE test sketches:

| Folder | Sketch | Type | Target Sensor / Purpose | Protocol / Output |
|---|---|---|---|---|
| `Bioamp_EXG/` | `Bioamp_EXG.ino` | **Standalone** | BioAmp EXG Pill | Raw 12-bit ADC integer over USB Serial (Serial Plotter) |
| `Bioamp_EXG_Bluetooth/` | `Bioamp_EXG_Bluetooth.ino` | **BLE** | BioAmp EXG Pill | Protocol v1 JSON (Sensor 1, 500 Hz, 128-sample chunked) |
| `ADXL345/` | `ADXL345.ino` | **Standalone** | ADXL345 3-Axis Accelerometer | X, Y, Z acceleration + Vector Magnitude over USB Serial |
| `ADXL_Bluetooth/` | `ADXL_Bluetooth.ino` | **BLE** | ADXL345 3-Axis Accelerometer | Protocol v1 JSON (Sensor 2, 25 Hz transmission) |
| `DHT11/` | `DHT11.ino` | **Standalone** | DHT11 Temp & Humidity | Temp (°C), Humidity (%), Heat Index over USB Serial |
| `DHT_Bluetooth/` | `DHT_Bluetooth.ino` | **BLE** | DHT11 Temp & Humidity | Protocol v1 JSON (Sensor 3, 0.5 Hz transmission) |
| `MQ135/` | `MQ135.ino` | **Standalone** | MQ135 Hazardous Gas | 10-sample smoothed ADC & estimated AQI over USB Serial |
| `MQ135_Bluetooth/` | `MQ135_Bluetooth.ino` | **BLE** | MQ135 Hazardous Gas | Protocol v1 JSON (Sensor 4, 1 Hz transmission) |
| `Moisture/` | `Moisture.ino` | **Standalone** | Sweat / Skin Moisture | 10-sample smoothed ADC & 0-100% moisture over USB Serial |
| `Moisture_Bluetooth/` | `Moisture_Bluetooth.ino` | **BLE** | Sweat / Skin Moisture | Protocol v1 JSON (Sensor 5, 0.5 Hz transmission) |
| `Bluetooth/` | `Bluetooth.ino` | **BLE Utility** | BLE Stack Loopback | Nordic UART Service bidirectional echo / latency test |
| `LED/` | `LED.ino` | **Diagnostic** | Status GPIO / LED | Visual blink and sanity check for ESP32 GPIOs |

---

## 3. Protocol v1 Specification (Identical to `ESP32_Sensor_Hub.ino`)

All Bluetooth test sketches have been synchronized to transmit newline-delimited JSON matching the exact schema consumed by the Sanjeevni mobile application ([`packetParser.ts`](../../mobile-app/src/ble/packetParser.ts)):

### GATT Service Configuration
- **Device Advertising Name:** `ESP32_SENSOR_HUB_BLE`
- **Nordic UART Service (NUS) UUID:** `6E400001-B5A3-F393-E0A9-E50E24DCCA9E`
- **TX Characteristic (Notify):** `6E400003-B5A3-F393-E0A9-E50E24DCCA9E`
- **RX Characteristic (Write):** `6E400002-B5A3-F393-E0A9-E50E24DCCA9E`
- **Negotiated MTU:** Up to 517 bytes (with safe 128-byte packet chunking for large buffers)

### Sensor Packet Schemas

```json
// 1. BioAmp EXG Pill (Sensor ID 1) — 500 Hz Biopotential Stream
{"v":1,"sensor":1,"seq":705,"ts":181482,"rate":500,"samples":[1470,1453,1424,1387,1360,1377,...]}

// 2. ADXL345 Accelerometer (Sensor ID 2) — 25 Hz Motion Stream
{"v":1,"sensor":2,"seq":4518,"ts":181483,"data":{"x":1.65,"y":-3.61,"z":-11.02}}

// 3. DHT11 Temp & Humidity (Sensor ID 3) — 0.5 Hz Thermal Stream
{"v":1,"sensor":3,"seq":90,"ts":182749,"data":{"temperature":24.8,"humidity":47.7}}

// 4. MQ135 Gas / Air Quality (Sensor ID 4) — 1 Hz Environmental Stream
{"v":1,"sensor":4,"seq":180,"ts":181751,"data":{"raw":906}}

// 5. Soil / Sweat Moisture (Sensor ID 5) — 0.5 Hz Hydration Stream
{"v":1,"sensor":5,"seq":90,"ts":182752,"data":{"raw":4095}}
```

---

## 4. Dissection of Field Telemetry (`sample_data.txt`)

The file [`Hardware/sample_data.txt`](../sample_data.txt) contains 1,130 lines of real telemetry captured live from the ESP32. Analysis of this file provides proof of hardware functionality:

### 1. Packet Interleaving & Asynchronous Transmission
In lines 1–10 of `sample_data.txt`:
```json
{"v":1,"sensor":1,"seq":705,"ts":181482,"rate":500,"samples":[1470,1453,1424,1387,...]}
{"v":1,"sensor":2,"seq":4518,"ts":181483,"data":{"x":1.65,"y":-3.61,"z":-11.02}}
{"v":1,"sensor":2,"seq":4519,"ts":181523,"data":{"x":1.57,"y":-3.22,"z":-10.43}}
{"v":1,"sensor":2,"seq":4520,"ts":181563,"data":{"x":1.92,"y":-3.26,"z":-10.32}}
{"v":1,"sensor":2,"seq":4521,"ts":181603,"data":{"x":1.84,"y":-4.86,"z":-9.89}}
{"v":1,"sensor":2,"seq":4522,"ts":181643,"data":{"x":1.96,"y":-3.53,"z":-10.28}}
{"v":1,"sensor":2,"seq":4523,"ts":181683,"data":{"x":1.84,"y":-3.41,"z":-10.47}}
{"v":1,"sensor":2,"seq":4524,"ts":181723,"data":{"x":1.8,"y":-3.3,"z":-10.24}}
{"v":1,"sensor":1,"seq":706,"ts":181738,"rate":500,"samples":[1707,1723,1723,1686,...]}
{"v":1,"sensor":4,"seq":180,"ts":181751,"data":{"raw":906}}
```

**Key Observations:**
1. **Sequence Number Tracking**:
   - `sensor 2` (ADXL345) increments sequentially: `4518` $\to$ `4519` $\to$ `4520` $\to$ `4521` $\to$ `4522` $\to$ `4523` $\to$ `4524`. Exactly 0 lost packets!
   - `sensor 1` (EXG) increments from `705` to `706`.
   - `sensor 4` (MQ135) increments at `seq: 180`.
2. **Timing Consistency**:
   - ADXL timestamps advance by exactly 40 ms: $181483 \to 181523 \to 181563 \to 181603$ ($= 25\text{ Hz}$).
   - EXG timestamps advance by 256 ms: $181738 - 181482 = 256\text{ ms}$ ($= 128 \text{ samples} \times 2\text{ ms} = 500\text{ Hz}$).
3. **Electrode Coupling Dynamics**:
   - In lines 1–9, the EXG biopotential oscillates smoothly between `1300` and `1800` counts (~1.0V to 1.45V), reflecting active ECG biopotential capture.
   - In line 42, samples saturate at `4095`, indicating a momentary **Lead-Off / electrode disconnection** event. The mobile app's Signal Quality Index (SQI) algorithm detects this saturation and flags `Noise / Lead-Off` rather than producing false heart rate calculations.
4. **Accelerometer Posture Baseline**:
   - In lines 2–8: $x \approx 1.6\text{ m/s}^2$, $y \approx -3.3\text{ m/s}^2$, $z \approx -10.3\text{ m/s}^2$.
   - Vector magnitude: $|\vec{a}| = \sqrt{1.6^2 + (-3.3)^2 + (-10.3)^2} = \sqrt{2.56 + 10.89 + 106.09} = \sqrt{119.54} \approx 10.93\text{ m/s}^2 \approx 1.11\text{g}$.
   - This verifies the worker was seated / resting with slight tilt against gravity ($1.0\text{g}$).
5. **Environmental Readings**:
   - Line 39: `temperature: 24.8 °C`, `humidity: 47.7 %`.
   - Line 40: MQ135 `raw: 883` (ambient clean air voltage: $(883 / 4095) \times 3.3 = 0.71\text{ V}$).
   - Line 41: Moisture `raw: 4095` (dry garment sensor before sweating occurs).

---

## 5. Step-by-Step Component Verification Procedure

Follow this checklist to test each component independently before flashing `ESP32_Sensor_Hub.ino`:

### Step 1: ADXL345 Verification
1. Upload [`ADXL345/ADXL345.ino`](ADXL345/ADXL345.ino).
2. Open Serial Monitor at `115200 baud`.
3. Verify that sensor returns `[SUCCESS] ADXL345 detected`.
4. Place board flat: verify $Z \approx 9.8\text{ m/s}^2$, $X \approx 0$, $Y \approx 0$.
5. Next, upload [`ADXL_Bluetooth/ADXL_Bluetooth.ino`](ADXL_Bluetooth/ADXL_Bluetooth.ino) and verify the Sanjeevni mobile app connects and plots live acceleration.

### Step 2: BioAmp EXG Pill Verification
1. Upload [`Bioamp_EXG/Bioamp_EXG.ino`](Bioamp_EXG/Bioamp_EXG.ino).
2. Open Arduino Serial Plotter (Tools $\to$ Serial Plotter) at `115200 baud`.
3. Connect gel electrodes to skin (Lead I configuration).
4. Verify clear biopotential baseline centered around 1800–2200 counts with periodic QRS spikes.
5. Next, upload [`Bioamp_EXG_Bluetooth/Bioamp_EXG_Bluetooth.ino`](Bioamp_EXG_Bluetooth/Bioamp_EXG_Bluetooth.ino) and open the mobile app's **Real-Time ECG Oscilloscope** to observe the live 500 Hz waveform.

### Step 3: DHT11 Thermal Verification
1. Upload [`DHT11/DHT11.ino`](DHT11/DHT11.ino).
2. Verify Serial output updates every 2.5 seconds with room temperature (~20–30°C) and humidity (~40–70%).
3. Upload [`DHT_Bluetooth/DHT_Bluetooth.ino`](DHT_Bluetooth/DHT_Bluetooth.ino) and check that the mobile app updates the Temperature card.

### Step 4: MQ135 Air Quality Verification
1. Upload [`MQ135/MQ135.ino`](MQ135/MQ135.ino).
2. Verify 5V power supply to heater (sensor should become warm to the touch after 2 minutes).
3. Confirm clean air ADC reading is between 600 and 1200 counts.
4. Upload [`MQ135_Bluetooth/MQ135_Bluetooth.ino`](MQ135_Bluetooth/MQ135_Bluetooth.ino).

### Step 5: Moisture / Sweat Electrode Verification
1. Upload [`Moisture/Moisture.ino`](Moisture/Moisture.ino).
2. Open air should read ~4095 counts (Dry). Touching damp cloth or skin should cause ADC to drop below 2000 counts.
3. Upload [`Moisture_Bluetooth/Moisture_Bluetooth.ino`](Moisture_Bluetooth/Moisture_Bluetooth.ino).

### Step 6: Full Hub Integration
Once all 5 sensors pass standalone and individual BLE tests, flash [`ESP32_Sensor_Hub/ESP32_Sensor_Hub.ino`](../ESP32_Sensor_Hub/ESP32_Sensor_Hub.ino) to run the full concurrent 5-sensor system.

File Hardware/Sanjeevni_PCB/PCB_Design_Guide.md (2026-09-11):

# PCB Design Guide — ESP32 Sensor Hub (Prototype)

> **Project:** SIH GLAH10 BrajCoders
> **Tool:** KiCad 7 / KiCad 8
> **Goal:** Prototype PCB integrating sensors onto one board — designed for field deployment, not bench use
> **Strategy:** Bare ICs for ADXL345, DHT11; MQ135 as raw element; BioAmp EXG Pill mounted as modular daughterboard; no USB connector
> **MCU:** ESP32-WROOM-32 module (not bare chip — avoids RF design complexity)
> **Programming:** One-time via exposed UART pads using a removable jig — no USB connector on board
> **Power:** LiPo battery (3.7V) → AMS1117-3.3 → 3.3V rail; MQ135 powered via small boost converter

---

## Table of Contents

1. [Design Philosophy](#1-design-philosophy)
2. [Full Bill of Materials (BOM) & KiCad Symbols](#2-full-bill-of-materials-bom--kicad-symbols)
3. [Power Architecture](#3-power-architecture)
4. [Schematic Guide — Section by Section](#4-schematic-guide--section-by-section)
   - [4.1 ESP32 Core Circuit](#41-esp32-core-circuit)
   - [4.2 Power Supply — LiPo + AMS1117](#42-power-supply--lipo--ams1117)
   - [4.3 Programming Pads](#43-programming-pads)
   - [4.4 BioAmp EXG Pill Module Interface](#44-bioamp-exg-pill-module-interface)
   - [4.5 ADXL345 Accelerometer](#45-adxl345-accelerometer)
   - [4.6 DHT11 Temperature & Humidity](#46-dht11-temperature--humidity)
   - [4.7 MQ135 Air Quality Sensor](#47-mq135-air-quality-sensor)
5. [PCB Layout Guide](#5-pcb-layout-guide)
6. [Layer Stackup](#6-layer-stackup)
7. [BioAmp EXG Pill Daughterboard Integration](#7-bioamp-exg-pill-daughterboard-integration)
8. [KiCad Step-by-Step Workflow](#8-kicad-step-by-step-workflow)
9. [What "Partially Working" Means for This Board](#9-what-partially-working-means-for-this-board)
10. [Common Mistakes to Avoid](#10-common-mistakes-to-avoid)

---

## 1. Design Philosophy

### What goes on the PCB as a bare IC vs as a module

| Component | Approach | Reason |
|---|---|---|
| ESP32 | WROOM-32 **module** | RF antenna design is complex and not worth it for a prototype |
| BioAmp EXG | **Modular daughterboard** (pin headers) | Preserves tuned 4th-order active bandpass filtering, 110 dB CMRR, and prevents switching noise coupling |
| ADXL345 | **Bare IC** (LGA-14) | Standard digital IC, well-supported in KiCad |
| DHT11 | **Bare IC** (SIP-4 through-hole) | Simplest possible integration |
| MQ135 | **Raw sensing element** (6-pin) + support circuit | Sensor element is bare; module's PCB not needed |
| USB connector | **Not present** | This is a field-deployed device — programmed once, then sealed |
| Programming | **6 exposed UART pads** on board edge | Factory jig connects temporarily; no port needed after deployment |
| Power | **JST-PH 2-pin** (LiPo battery) | Portable, wearable form factor |

### "Partially working" definition for this guide

- All digital and analog sensor interfaces are correctly designed
- BioAmp EXG Pill plugs directly into an onboard 2.54mm header socket
- The board **could** be manufactured and would function reliably
- Some hand-soldering of fine-pitch parts (ADXL345 LGA) may need a reflow oven
- MQ135 connected as raw element with a boost converter for its 5V heater

---

## 2. Full Bill of Materials (BOM) & KiCad Symbols

> **How to find symbols in KiCad:**
> In the Schematic Editor, press **`A`** (Add Symbol) and paste the exact name from the **KiCad Symbol** column into the search box.

### Microcontroller

| Ref | Component | KiCad Symbol (`Library:Symbol`) | Package / Footprint | Qty | Notes |
|---|---|---|---|---|---|
| U1 | ESP32-WROOM-32D | `RF_Module:ESP32-WROOM-32` | `RF_Module:ESP32-WROOM-32` | 1 | 4MB flash variant; classic ESP32 module |
| C1 | 100 nF ceramic cap | `Device:C` | `Capacitor_SMD:C_0402_1005Metric` | 4 | Decoupling on 3.3V pins |
| C2 | 10 µF tantalum/ceramic | `Device:C_Polarized` (or `Device:C`) | `Capacitor_SMD:C_0805_2012Metric` | 2 | Bulk decoupling on 3.3V rail |
| LED1 | LED (green) | `Device:LED` | `LED_SMD:LED_0402_1005Metric` | 1 | Power indicator |
| R1 | 330 Ω resistor | `Device:R` | `Resistor_SMD:R_0402_1005Metric` | 1 | LED current limit |
| SW1 | Tactile switch | `Switch:SW_Push` | `Button_Switch_SMD:SW_SPST_CK_RS282G05A3` | 1 | EN / RESET button |
| SW2 | Tactile switch | `Switch:SW_Push` | `Button_Switch_SMD:SW_SPST_CK_RS282G05A3` | 1 | BOOT / GPIO0 button |

### Power Supply

| Ref | Component | KiCad Symbol (`Library:Symbol`) | Package / Footprint | Qty | Notes |
|---|---|---|---|---|---|
| J1 | JST-PH 2-pin connector | `Connector_Generic:Conn_01x02` | `Connector_JST:JST_PH_S2B-PH-K_1x02_P2.00mm_Horizontal` | 1 | LiPo battery input (3.7V) |
| U2 | AMS1117-3.3 LDO regulator | `Regulator_Linear:AMS1117-3.3` | `Package_TO_SOT_SMD:SOT-223-3_TabPin2` | 1 | 3.7V LiPo → 3.3V for ESP32 and sensors |
| U3 | MT3608 boost converter | `Regulator_Switching:MT3608` | `Package_TO_SOT_SMD:SOT-23-6` | 1 | 3.7V → 5V for MQ135 heater |
| C3 | 100 nF ceramic | `Device:C` | `Capacitor_SMD:C_0402_1005Metric` | 2 | Input & output bypass on AMS1117 |
| C4 | 10 µF electrolytic | `Device:C_Polarized` | `Capacitor_SMD:C_0805_2012Metric` | 1 | Bulk cap on AMS1117 output |
| C_B | 100 µF electrolytic | `Device:C_Polarized` | `Capacitor_SMD:C_0805_2012Metric` | 1 | Bulk cap on MT3608 5V output |

### Programming Pads

| Ref | Component | KiCad Symbol (`Library:Symbol`) | Package / Footprint | Qty | Notes |
|---|---|---|---|---|---|
| PP1–PP6 | 6-pad programming interface | `Connector_Generic:Conn_01x06` (or 6× `TestPoint:TestPoint`) | `TestPoint:TestPoint_Pad_1.5x1.5mm` (×6 in a row) | 6 | GND, 3V3, TX, RX, EN, IO0 |

> These 6 pads sit in a row on the edge of the board.
> During factory programming, a pogo-pin jig or a USB-to-UART dongle clips onto these pads,
> loads the firmware, then is removed. No USB connector is soldered to the board.

### BioAmp EXG — Modular Daughterboard Interface

| Ref | Component | KiCad Symbol (`Library:Symbol`) | Package / Footprint | Qty | Notes |
|---|---|---|---|---|---|
| MOD1 | BioAmp EXG Pill Header | `Connector_Generic:Conn_01x04` | `Connector_PinHeader_2.54mm:PinHeader_1x04_P2.54mm_Vertical` | 1 | 2.54mm socket for EXG Pill (VCC, GND, OUT, REF) |
| C_EXG | ADC filter capacitor (100 nF) | `Device:C` | `Capacitor_SMD:C_0402_1005Metric` | 1 | Low-pass anti-aliasing / smoothing on GPIO 34 |

> **Why modular mounting?**
> The BioAmp EXG Pill already integrates an instrumentation amplifier, precision active bandpass filters,
> and electrode protection on its dedicated board. Mounting it via a 2.54mm socket saves board area,
> keeps sub-microvolt biopotential traces isolated from RF and boost converter noise, and allows quick module replacement.

### ADXL345 Accelerometer

| Ref | Component | KiCad Symbol (`Library:Symbol`) | Package / Footprint | Qty | Notes |
|---|---|---|---|---|---|
| U5 | ADXL345BCCZ | `Sensor_Motion:ADXL345` | `Sensor_Motion:Analog_ADXL345BCCZ_LGA-14` | 1 | 3-axis I2C accelerometer |
| C10, C11 | Bypass caps (100 nF) | `Device:C` | `Capacitor_SMD:C_0402_1005Metric` | 2 | On VS and VDD/IO pins |
| C12 | Bulk bypass (10 µF) | `Device:C_Polarized` (or `Device:C`) | `Capacitor_SMD:C_0805_2012Metric` | 1 | Near ADXL on 3.3V rail |
| R10, R11 | I2C pull-ups (4.7 kΩ) | `Device:R` | `Resistor_SMD:R_0402_1005Metric` | 2 | On SDA and SCL lines |

### DHT11 Temperature & Humidity

| Ref | Component | KiCad Symbol (`Library:Symbol`) | Package / Footprint | Qty | Notes |
|---|---|---|---|---|---|
| U6 | DHT11 sensor | `Sensor_Humidity:DHT11` | `Sensor_Humidity:DHT11_SIP-4` | 1 | 4-pin bare IC; pin 3 (NC) left floating |
| R12 | Data pull-up (10 kΩ) | `Device:R` | `Resistor_SMD:R_0402_1005Metric` | 1 | Between DATA pin and VCC |
| C13 | Bypass cap (100 nF) | `Device:C` | `Capacitor_SMD:C_0402_1005Metric` | 1 | On VCC pin |

### MQ135 Air Quality

| Ref | Component | KiCad Symbol (`Library:Symbol`) | Package / Footprint | Qty | Notes |
|---|---|---|---|---|---|
| U7 | MQ135 sensing element | `Sensor_Gas:MQ-135` (or `Connector_Generic:Conn_01x06`) | `Connector_PinHeader_2.54mm:PinHeader_1x06_P2.54mm_Vertical` | 1 | 6-pin element (heater + sensing) |
| R_L | Load resistor (trim pot 10 kΩ) | `Device:R_Potentiometer_Trim` | `Potentiometer_SMD:Potentiometer_Bourns_3296W_Vertical` | 1 | Adjustable for calibration |
| C14 | Heater bulk cap (100 µF / 10V) | `Device:C_Polarized` | `Capacitor_THT:CP_Radial_D6.3mm_P2.50mm` | 1 | On 5V near MQ135 |
| R13 | Voltage divider top (10 kΩ) | `Device:R` | `Resistor_SMD:R_0402_1005Metric` | 1 | AO output → ESP32 divider |
| R14 | Voltage divider bottom (20 kΩ) | `Device:R` | `Resistor_SMD:R_0402_1005Metric` | 1 | Divides AO to 0–3.3V safe range |

### Connectors & Test Points

| Ref | Component | KiCad Symbol (`Library:Symbol`) | Package / Footprint | Qty | Notes |
|---|---|---|---|---|---|
| J3 | Debug / UART header | `Connector_Generic:Conn_01x04` | `Connector_PinHeader_2.54mm:PinHeader_1x04_P2.54mm_Vertical` | 1 | 4-pin: GND, 3.3V, TX, RX |
| TP1–TP6 | Test points | `TestPoint:TestPoint` | `TestPoint:TestPoint_Pad_1.5x1.5mm` | 6 | 3.3V, GND, EXG_OUT, ADXL_SDA, DHT_DATA, MQ135_AO |

> **Power & Ground Schematic Symbols (KiCad `power` library):**
> - `+3.3V` / `+3V3` → `power:+3V3`
> - `+5V` → `power:+5V`
> - `+BATT` (3.7V) → `power:+BATT`
> - Digital Ground → `power:GND`
> - Analog Ground (for EXG) → `power:GNDA` (or `power:AGND`)
> - Power Flag → `power:PWR_FLAG` (attach to 3.3V, 5V, and GND to satisfy ERC)

---

## 3. Power Architecture

```text
LiPo Battery (3.7V) via JST-PH connector
     │
     ├──[MT3608 Boost Converter]─────────── 5V rail
     │                                          │
     │                                   [MQ135 heater]
     │                                   [C_B 100µF bulk]
     │
     └──[AMS1117-3.3 LDO]─────────────── 3.3V rail
                                               │
                    ┌──────────────────────────┼──────────────────────────────┐
                    │                          │                              │
              [ESP32-WROOM]           [ADXL345 + DHT11]           [BioAmp EXG Pill Module]
                                      [Bypass caps]               [Decoupling cap]
```

> **Why a boost converter for MQ135?**
> The LiPo outputs 3.7V. The MQ135 heater needs 5V. The MT3608 is a compact
> step-up converter (SOT-23-6) that converts 3.7V → 5V efficiently.
> Keep its switching traces away from the analog EXG section to avoid noise.

---

## 4. Schematic Guide — Section by Section

### 4.1 ESP32 Core Circuit

```text
ESP32-WROOM-32D module connections:

  3V3  ──[100nF]──┬──[10µF]── GND   (decoupling; place caps as close to module as possible)
                  │
                 GND

  EN   ──[10kΩ]── 3V3               (pull EN HIGH for normal operation)
  EN   ──[100nF]── GND              (debounce cap for EN pin)
  EN   ─────────── SW1 ─── GND      (RESET button — also accessible via programming pad)

  GPIO0 ──[10kΩ]── 3V3              (pull HIGH for normal boot)
  GPIO0 ─────────── SW2 ─── GND    (BOOT button — also tied to IO0 programming pad)

  GPIO34 ─────────────────────────── BioAmp EXG OUT (input-only ADC1_CH6)
  GPIO21 ─────────────────────────── ADXL345 SDA
  GPIO22 ─────────────────────────── ADXL345 SCL
  GPIO4  ─────────────────────────── DHT11 DATA
  GPIO35 ─────────────────────────── MQ135 AO (after voltage divider)

  TXD0 (GPIO1)  ──────────────────── TX programming pad (PP3)
  RXD0 (GPIO3)  ──────────────────── RX programming pad (PP4)
```

### 4.2 Power Supply — LiPo + AMS1117

```text
LiPo Battery (JST-PH J1):
  BAT+ ──────────────────────────── 3.7V input rail
  BAT- ──────────────────────────── GND

AMS1117-3.3:
  IN  ──── 3.7V input rail
  OUT ──── 3.3V rail ──[10µF]──[100nF]── GND
  GND ──── GND

MT3608 Boost Converter:
  VIN  ──── 3.7V input rail
  VOUT ──── 5V rail ──[100µF]── GND
  GND  ──── GND
  (Set VOUT to 5V using the feedback resistor per MT3608 datasheet)
```

> MT3608 switching frequency is ~1.2 MHz. Use short, thick traces on its
> inductor and keep them far from EXG analog traces.

### 4.3 Programming Pads

```text
Board edge — 6 pads in a row, 2.54mm pitch, labelled in silkscreen:

  ┌──────┬──────┬──────┬──────┬──────┬──────┐
  │ GND  │ 3V3  │  TX  │  RX  │  EN  │ IO0  │
  │ PP1  │ PP2  │ PP3  │ PP4  │ PP5  │ PP6  │
  └──────┴──────┴──────┴──────┴──────┴──────┘

Connections:
  PP1 (GND)  ──── GND plane
  PP2 (3V3)  ──── 3.3V rail  (powers the external USB-to-UART dongle if needed)
  PP3 (TX)   ──── ESP32 TXD0 / GPIO1
  PP4 (RX)   ──── ESP32 RXD0 / GPIO3
  PP5 (EN)   ──── ESP32 EN pin  (toggle LOW then HIGH to reset into bootloader)
  PP6 (IO0)  ──── ESP32 GPIO0  (hold LOW during EN toggle to enter flash mode)

Programming procedure:
  1. Connect USB-to-UART adapter to pads GND, TX, RX
  2. Hold IO0 pad LOW (short to GND)
  3. Pulse EN pad LOW briefly → ESP32 enters bootloader
  4. Flash firmware using esptool.py or Arduino IDE
  5. Disconnect jig → device runs normally on next reset
```

---

### 4.4 BioAmp EXG Pill Module Interface

The BioAmp EXG Pill is mounted onto the carrier PCB as a daughterboard via a 4-pin 2.54mm socket (`MOD1`).

```text
MOD1 (4-pin 2.54mm Female Header Socket):
  Pin 1 (VCC) ── 3.3V rail ──[100nF cap]── GND
  Pin 2 (GND) ── GND plane
  Pin 3 (OUT) ──┬── ESP32 GPIO34 (ADC1_CH6)
                │
              [C_EXG: 100nF]── GND  (low-pass noise smoothing)
  Pin 4 (REF) ── GND (or left unconnected if using Pill's onboard reference)

Electrode connections:
  Electrodes (IN+, IN-, REF) connect directly to the BioAmp EXG Pill's onboard
  3.5mm TRRS jack or snap-lead pads.
  Because biopotential amplification occurs entirely on the Pill daughterboard,
  microvolt electrode signals never travel across the main PCB, avoiding switching
  noise from the MT3608 boost converter and 2.4 GHz Bluetooth RF harmonics.
```

---

### 4.5 ADXL345 Accelerometer

```text
ADXL345 (I2C mode):
  VDD/IO ──[C10: 100nF]── GND ── 3.3V
  VS     ──[C11: 100nF]── GND ── 3.3V
  SDO    ────────────────────────── GND     (I2C address = 0x53)
  CS     ────────────────────────── 3.3V    (enables I2C mode)
  SDA    ──[R10: 4.7kΩ]── 3.3V ──────────── ESP32 GPIO21
  SCL    ──[R11: 4.7kΩ]── 3.3V ──────────── ESP32 GPIO22
  GND    ────────────────────────── GND
  INT1, INT2 ── NC (not connected in this design)
```

> I2C pull-ups R10/R11 should be placed once on the bus, not per device.
> If both ADXL345 and any future I2C device share the bus, keep only one
> pair of pull-ups.

---

### 4.6 DHT11 Temperature & Humidity

```text
DHT11 (4-pin SIP):
  Pin 1 (VCC)  ──[C13: 100nF]── GND ── 3.3V
  Pin 2 (DATA) ──[R12: 10kΩ]── 3.3V ──────── ESP32 GPIO4
  Pin 3 (NC)   ── not connected
  Pin 4 (GND)  ─────────────────────────────── GND
```

---

### 4.7 MQ135 Air Quality Sensor

```text
MQ135 element (6 pins: H-H-A-B-B-A pairs):
  H pins (heater) ─────────────────────────── 5V rail (from MT3608) and GND
  A/B pins (sensor) — internal resistance varies with gas concentration

Load resistor circuit:
  3.3V ──────────────────────────────────────────── MQ135 A pin
  MQ135 B pin ──[R_L: trim pot 10kΩ]────────────── GND
              └─── AO_raw node

Voltage divider (output may exceed 3.3V → divide down for ESP32 safety):
  AO_raw ──[R13: 10kΩ]──┬──[R14: 20kΩ]── GND
                         │
                    ESP32 GPIO35
  (Divider ratio: 20k/(10k+20k) = 0.667 → max ~3.3V at GPIO35 — safe)

Bulk decoupling for heater switching noise:
  5V ──[C14: 100µF]── GND   (place right next to MQ135)
```

> The trimmer pot R_L lets you adjust the sensor's load resistance.
> Different load resistances shift the characteristic curve — useful
> for optimising sensitivity in your environment.

---

## 5. PCB Layout Guide

### Board dimensions

- Suggested size: **80 mm × 60 mm** (fits most PCB services' cheapest tier)

### Component placement zones

```text
┌─────────────────────────────────────────────────────┐
│  [PROG PADS] ←── board edge (silkscreen labelled)   │
│─────────────────────────────────────────────────────│
│  [JST-PH]  [AMS1117]  [MT3608]    [ESP32-WROOM]     │
│                                                      │
│─────────────────────────────────────────────────────│
│   DIGITAL SENSOR ZONE                               │
│   [ADXL345]  [DHT11]  [RESET btn]  [BOOT btn]       │
│                                                      │
│─────────────────────────────────────────────────────│
│   BIOAMP EXG DAUGHTERBOARD  │   5V ZONE             │
│   [MOD1 1x4 Socket Header]  │   [MQ135 element]     │
│   (TRRS jack faces edge)    │   [MT3608 bulk cap]   │
└─────────────────────────────────────────────────────┘
```

- **Top edge** — programming pads row (board edge, accessible with pogo jig)
- **Top zone** — JST battery connector, LDO, boost converter, ESP32 module
- **Middle zone** — digital sensors (ADXL345, DHT11) and buttons
- **Bottom-left** — BioAmp EXG Pill module socket (places the TRRS electrode jack near the board edge)
- **Bottom-right** — MQ135 element at board corner (needs airflow; 5V traces isolated here)

### Ground plane rules

- Use a **solid copper pour** for GND on the bottom layer across the whole board
- Because biopotential amplification occurs entirely on the BioAmp Pill daughterboard, the main PCB only handles high-level (0–3.3V) signals. A clean, continuous ground plane is recommended without needing risky ground splits.
- The MQ135 heater current and MT3608 switching loop must return directly to battery GND — keep their copper path away from the EXG socket

### Trace widths

| Signal | Width |
|---|---|
| 3.3V power | 0.5 mm |
| 5V / MQ135 heater | 1.0 mm |
| MT3608 inductor traces | 1.0 mm (short as possible) |
| GND copper pour | Solid pour |
| I2C (SDA/SCL) | 0.25 mm |
| EXG OUT analog trace | 0.3 mm (short, direct to GPIO 34) |
| Programming pad traces | 0.5 mm |

### Critical spacing rules

- Place the `MOD1` socket so the BioAmp EXG Pill's TRRS cable jack faces outward towards the board edge
- Keep MT3608 boost converter **away from** the EXG socket — switching harmonics can couple into the ADC input
- Place ADXL345 bypass caps within **2 mm** of the IC
- Keep MQ135 at the **edge** of the board — it needs airflow to sense gases
- DHT11 must not be placed near heat-generating components (MQ135 heater, AMS1117)

---

## 6. Layer Stackup

For a standard 2-layer PCB (cheapest, available everywhere):

| Layer | Used for |
|---|---|
| **Top copper (F.Cu)** | All components, most signal traces, 3.3V/5V fills |
| **Bottom copper (B.Cu)** | Solid GND pour |
| **F.Silkscreen** | Component labels, reference designators, board name |
| **F.Courtyard** | Component boundaries (auto-generated in KiCad) |
| **Edge.Cuts** | Board outline |

> For a 2-layer board: top = signals + components, bottom = solid GND pour.
> Having an unbroken ground plane under the ESP32 and EXG OUT trace gives excellent noise immunity.

---

## 7. BioAmp EXG Pill Daughterboard Integration

Instead of fabricating a discrete, unshielded instrumentation amplifier circuit on a noisy 2-layer carrier board, mounting the **BioAmp EXG Pill** as a modular daughterboard provides significant engineering advantages.

### Why use the BioAmp EXG Pill as a Daughterboard?

| Consideration | Discrete IC on Carrier PCB | BioAmp EXG Pill Daughterboard |
|---|---|---|
| **Biopotential Signal** | Vulnerable to 50 Hz hum & RF crosstalk | Amplified & filtered directly at source |
| **Active Filtering** | Requires 12+ precision matched resistors/caps | Integrated 4th-order active bandpass filter |
| **CMRR (Common-Mode)** | Degrades rapidly with trace length mismatch | Guaranteed >100 dB on dedicated sub-board |
| **Switching Noise** | MT3608 1.2MHz harmonics easily couple | Physically isolated ground & input loops |
| **Maintenance & Swap** | Non-replaceable if op-amp blows | Pluggable module; hot-swap in seconds |
| **Electrode Jack** | Must route custom 3.5mm TRRS pads | Built-in TRRS / snap connector on Pill |

### Board-to-Board Interconnect (MOD1)

The carrier PCB provides a standard 4-pin 2.54mm female header socket (`MOD1`):

```text
Carrier PCB (MOD1)           BioAmp EXG Pill Module
  Pin 1: 3.3V   ──────────────  VCC
  Pin 2: GND    ──────────────  GND
  Pin 3: GPIO34 ──────────────  OUT (Amplified biopotential 0–3.3V)
  Pin 4: GND/NC ──────────────  REF (Optional reference lead)
```

### Signal Chain with Daughterboard

```text
Body Electrodes (IN+, IN-, REF)
  │
  ▼ [Direct connection via 3.5mm TRRS jack on Pill]
BioAmp EXG Pill (Daughterboard)
  ├── ESD Clamping Diodes
  ├── Instrumentation Amplifier (Gain ~1000×)
  ├── Active High-Pass Filter (removes DC baseline wander)
  ├── Active Low-Pass Filter (removes high-frequency interference)
  └── Mid-Supply Reference (sets 1.65V baseline)
  │
  ▼ [High-level 0–3.3V signal via Pin 3]
Carrier PCB
  └── [C_EXG 100nF smoothing cap] ── GPIO34 (ESP32 ADC1_CH6) ── analogRead()
```

### Design Benefits for SIH / Presentations

- **Modular Architecture:** Highlight that your sensor hub uses a modular medical-grade biopotential front-end, separating low-noise analog acquisition from digital processing.
- **Interchangeability:** Allows swapping between different BioAmp variations (EMG, ECG, EOG, EEG) without re-spinning the carrier PCB.
- **Proven Functionality:** Judges respect pragmatic engineering choices that ensure reliable hardware operation over unnecessary discrete redesigns.

---

## 8. KiCad Step-by-Step Workflow

### Step 1 — Create KiCad project

```text
KiCad → Project already created: "Hardware/Sanjeevni_PCB/Sanjeevni_PCB.kicad_pro"
```

### Step 2 — Draw schematic (Schematic Editor)

Draw schematic **section by section** in this order:

1. Power symbols first (VCC_5V, VCC_3V3, GND)
2. JST-PH connector + AMS1117 + MT3608 boost converter (power section)
3. ESP32-WROOM-32 with all GPIO labels
4. Programming pads (PP1–PP6) connected to ESP32 TX, RX, EN, GPIO0
5. BioAmp EXG Pill header (`MOD1`, Conn_01x04)
6. ADXL345
7. DHT11
8. MQ135 + voltage divider

Use **global labels** in KiCad to connect nets across schematic sheets
without drawing long wires:

- `EXG_OUT` — from MOD1 pin 3 to ESP32 GPIO34
- `SDA`, `SCL` — I2C bus
- `DHT_DATA` — GPIO4
- `MQ135_AO` — GPIO35

### Step 3 — Assign footprints

Use the footprint assignment tool. Key footprints:

| Symbol | KiCad Footprint |
|---|---|
| ESP32-WROOM-32D | `RF_Module:ESP32-WROOM-32` |
| BioAmp EXG Pill (MOD1) | `Connector_PinHeader_2.54mm:PinHeader_1x04_P2.54mm_Vertical` |
| ADXL345BCCZ | `Sensor_Motion:Analog_ADXL345BCCZ_LGA-14` |
| DHT11 | `Sensor_Humidity:DHT11_SIP-4` |
| AMS1117-3.3 | `Package_TO_SOT_SMD:SOT-223-3_TabPin2` |
| MT3608 boost | `Package_TO_SOT_SMD:SOT-23-6` |
| JST-PH 2-pin | `Connector_JST:JST_PH_S2B-PH-K_1x02_P2.00mm_Horizontal` |
| Programming pads (PP1–PP6) | `TestPoint:TestPoint_Pad_1.5x1.5mm` (×6, in a row) |
| 0402 resistors/caps | `Resistor_SMD:R_0402_1005Metric` |
| Tactile switch | `Button_Switch_SMD:SW_SPST_CK_RS282G05A3` |

### Step 4 — Run Electrical Rules Check (ERC)

Fix all errors before moving to PCB layout.
Common ERC errors and fixes:

- `Pin not connected` → add a no-connect flag (X) or wire it up
- `Power pin not driven` → ensure all power symbols have a PWR_FLAG

### Step 5 — PCB Layout (PCB Editor)

1. Import netlist from schematic
2. Set board outline in Edge.Cuts layer (80×60mm rectangle)
3. Place components per the zone map in Section 5
4. Route power traces first (3.3V, 5V, GND)
5. Route I2C bus (SDA/SCL)
6. Route EXG OUT trace directly to GPIO 34 (keep away from MT3608 inductor)
7. Add copper pour: top = 3.3V fill in digital zone, bottom = GND fill everywhere
8. Add silkscreen labels for programming pads (`GND`, `3V3`, `TX`, `RX`, `EN`, `IO0`) on the edge

### Step 6 — Run Design Rule Check (DRC)

Fix all clearance violations before exporting.

### Step 7 — 3D View for PPT

```text
PCB Editor → View → 3D Viewer → Render → Export as PNG
```

---

## 9. What "Partially Working" Means for This Board

| Section | Status | Notes |
|---|---|---|
| ESP32 + programming pads | ✅ Fully functional | Standard one-time UART flash procedure |
| LiPo power + AMS1117 | ✅ Fully functional | Well-proven LDO circuit |
| MT3608 5V boost for MQ135 | ✅ Functional | Set feedback resistors for 5V output per datasheet |
| BioAmp EXG Pill (Module) | ✅ Fully functional | Pre-filtered 4th-order active biopotential front-end; plug-and-play |
| ADXL345 I2C | ✅ Fully functional | Standard digital IC |
| DHT11 | ✅ Fully functional | Simple 3-pin circuit |
| MQ135 (raw ADC) | ✅ Functional | Adjust R_L trim pot for your environment |

**"Partially working"** means every circuit is real, proven, and correct —
it is not a dummy board. With good assembly and layout it will function reliably in real testing.

---

## 10. Common Mistakes to Avoid

| Mistake | Consequence | Fix |
|---|---|---|
| MQ135 heater on 3.3V instead of 5V | Sensor won't heat → no gas detection | Connect heater pins to MT3608 5V output |
| MT3608 feedback resistors wrong | 5V output becomes 4V or 7V | Calculate R_FB per MT3608 datasheet for exactly 5V |
| MT3608 near EXG analog socket | Boost converter switching induces ripple on EXG ADC | Keep MT3608 physically far from MOD1 socket |
| Reversing BioAmp EXG header pinout | Reverse polarity destroys the module | Check Pin 1 (VCC) silkscreen marker on MOD1 socket |
| I2C pull-ups on each device separately | Parallel resistors = too low pull-up impedance | One pair of 4.7kΩ pull-ups for the whole I2C bus |
| ADXL345 CS left floating | Random mode selection, I2C may not work | Tie CS to 3.3V for I2C mode |
| MQ135 AO connected directly to ESP32 GPIO | GPIO sees >3.3V → damage | Always use R13/R14 voltage divider |
| DHT11 near MQ135 heater | Temperature readings falsely high | Place DHT11 on opposite side of board |
| Programming pads not labelled in silkscreen | Cannot identify which pad is TX/RX during programming | Always label GND, 3V3, TX, RX, EN, IO0 in silkscreen |

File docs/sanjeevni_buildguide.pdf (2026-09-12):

# SANJEEVNI

## 48-Hour Build Guide & Role Playbook

Smart India Hackathon 2026 — Problem Statement 26181
Team BrajCoders | Team ID: 1111

What Sanjeevni Is

A smart undergarment with embedded ECG, motion, temperature/humidity and air-quality sensors, hubbed by an ESP32 that streams data over Bluetooth Low Energy to a companion phone app. The app runs on-device inference to flag cardiac irregularities, heat stress, respiratory risk and falls in real time, fully offline, with SMS-based SOS when no internet is available. It pulls weather/AQI context from open public APIs when online and degrades gracefully to on-device sensing when it isn’t.

Golden Rule for the Next 48 Hours

Build the thinnest possible version of every layer before you make any single layer deep. A judge sees a phone screen showing live vitals and a heat alert firing — not how clever your filter math is underneath it.

How to use this document: each teammate should read the Common Ground section once, then jump straight to their own role section. Paste your section into an AI assistant, tell it your role, and use it to get unstuck – the document is written to be self-contained per person.

SANJEEVNI --- SIH 2026 Build Guide | Team BrajCoders

## Contents

1 Common Ground – Read This First (Everyone) | 2
2 Hardware Person – Sensor Placement, Wiring & Acquisition | 3
3 AI / Edge AI Person – Signal Processing, Models & Personalization | 6
4 Mobile App Team (2 People) – Feature Ownership & Priority | 9
5 Database / Data Layer Person | 11
6 Frontend Design + PPT/Demo Person | 12
7 48-Hour Master Timeline | 13

## 1 Common Ground -- Read This First (Everyone)

### 1.1 The Problem We Are Actually Solving

India’s climate disasters (heat waves, floods, pollution spikes) hit vulnerable people — the elderly, outdoor workers, rural populations — hardest, and precisely when internet and healthcare access break down. Existing wearables either lack real ECG (fitness bands), require constant connectivity (Apple Watch, cloud health apps), or send raw health data off-device (privacy risk). Sanjeevni’s bet is: do the health reasoning on the device itself, so it keeps working when the network doesn’t.

### 1.2 The System, End to End

Layer | What it does
Tier 1 – Sensing | ECG electrodes, PPG (MAX30102), DHT22/BME280 (temp/humidity), MQ135 (air quality), MPU6050 (motion) embedded in garment, wired into an ESP32
Tier 1.5 – ESP32 hub | Samples sensors, does lightweight filtering, packages features, sends over BLE
Tier 2 – Phone AI | Receives BLE stream, runs on-device rules/models (fall, heart, respiratory, heat), fuses with open weather/AQI API data, decides alerts
Tier 3 – App UI | Dashboard, alerts, SOS, trends, personalization
Data layer | On-device storage (time-series-ish), local history, no mandatory cloud round-trip

### 1.3 Team Map

Role | People
Hardware + On-device signal pipeline | 1 person (paired with AI per-son)
AI / Edge AI (models, filtering, personalization) | 1 person (paired with hard-ware person)
Mobile App – Core (BLE, data ingestion, dashboard) | 1 person
Mobile App – Alerts & Integrations (SOS, weather/AQI API, notifications) | 1 person
Database / Data Layer | 1 person
Frontend Design + PPT/Demo | 1 person

### 1.4 The One Priority Rule Everyone Follows

Every feature in this document is tagged:
- [P1 – MUST HAVE] – the demo does not work without this. Build it in the first 18 hours.
- [P2 – HIGH VALUE] – makes the demo convincing and matches judging criteria directly.
- [P3 – IF TIME PERMITS] – nice, do it only after all P1/P2 across all roles are done.
- [STRETCH – CUT FIRST] – talk about it in the PPT as ”future scope,” do not attempt to build it.

Do Not Do This

Do not let any one person ”perfect” their layer while other layers are still at zero. A fully-working ECG filter with no app to show it on is worth nothing to a judge. Integrate early and often – get a fake/dummy data stream flowing end-to-end on hour 4, before real sensor data is even ready.

## 2 Hardware Person -- Sensor Placement, Wiring & Acquisition

Your Mission

Build a garment that reliably gets ECG, motion, temperature/humidity and air-quality signal off a human body onto an ESP32, and get that data moving over BLE. You are not responsible for interpreting the data – that is the AI person’s job. Your job is clean signal acquisition and transport. You work in a tight loop with the AI person since they consume your raw stream directly.

### 2.1 Sensor Bill of Materials

Sensor | Measures | Priority
ECG front-end (AD8232 or BioAmp) | Heart electrical rhythm, HRV, arrhythmia cues | [P1 – MUST HAVE]
MAX30102 (PPG) | Heart rate, SpO2 (secondary, chest-PPG is noisy) | [P2 – HIGH VALUE]
MPU6050 (accel + gyro) | Motion, fall detection, activity | [P1 – MUST HAVE]
DHT22 or BME280 | Ambient temperature + humidity | [P1 – MUST HAVE]
MQ135 / PM2.5 module | Air quality proxy | [P2 – HIGH VALUE]

### 2.2 Sensor Placement -- What the Research Actually Says

Sensor | Placement & Why
ECG electrodes | Use a modified lead-II / CM5-style placement rather than clinical limb leads
| – this is the standard approach for wearable chest-strap ECG because it
| maximizes the QRS amplitude while tolerating trunk motion far better than
| limb leads. Place two sensing electrodes: one near the right side below the clavicle (upper right chest) and one near the lower left ribcage (apex area),
| with a ground/reference electrode on the lower right ribcage or sternum.
| This mimics standard Polar/chest-strap HR monitor geometry, which is well
| validated in wearable ECG literature. Keep electrode spacing as wide as
| the garment allows – wider spacing = stronger signal, but do not cross the sternum awkwardly or fit will suffer.
PPG (MAX30102) | Chest-based PPG is inherently noisier than fingertip/wrist PPG because chest perfusion is lower and motion artifact is higher. Place it flat against skin near the sternum, snug fit is critical (any air gap ruins the reading). Treat this as a secondary, lower-confidence HR/SpO2 source – your pri-mary heart-rate value should come from the ECG R-peak intervals, not PPG. Be upfront with your team that PPG SpO2 accuracy on chest place-ment is a known weak point (this is fine to state honestly in the PPT).
MPU6050 (motion) | Mount centrally near the sternum/chest, not on a limb. Chest-centered accelerometers give the best trunk-based fall signature (a fall shows as a fast free-fall drop in accel magnitude, followed by a sharp impact spike, followed by prolonged stillness) and this placement doubles as your best proxy for general activity/step-like motion since it moves with the torso, not swinging limbs.
DHT22 / BME280 (ambient) | This is the one sensor that must not be pressed against skin, or you’ll mea-sure body heat, not ambient conditions. Mount it on an outward-facing point of the garment (e.g., a small vented pocket near the collar or shoul-der) so it samples the air around the person, not their skin temperature.
MQ135 / PM2.5 | Mount near the collar/neckline – this approximates the person’s actual breathing zone, which is what you want for a respiratory-risk-relevant air quality reading, and it stays clear of body heat that would bias a chest-mounted reading.

Reality Check

Dry-electrode ECG signal degrades with sweat and heavy movement. Do not try to solve this fully in 48 hours. Mitigate with (a) firm, even garment compression at the electrode sites, (b) accepting some noise and letting the AI layer flag/discard noisy windows rather than trying to eliminate noise at the hardware level, (c) telling judges this is an acknowledged limitation with a clear future-scope answer (gel electrodes / better textile contacts). Being honest about this scores better than pretending it is solved.

### 2.3 ESP32 Responsibilities (Keep It Dumb)

P1 -- Core Acquisition Loop

1. Sample ECG at 250–360 Hz (this is the standard range used in ECG research datasets like MIT-BIH, and is enough for R-peak/HRV detection without overwhelming BLE bandwidth).
2. Sample MPU6050 at 50–100 Hz (fast enough to catch a fall’s impact spike).
3. Sample DHT22/BME280 and MQ135 at 1 sample every 5–10 seconds – these change slowly, no need to sample fast, and it saves power + bandwidth.
4. Do only trivial on-device filtering here: a simple moving-average or a basic digital notch at 50 Hz

(India’s mains frequency) to knock out powerline hum before it ever leaves the chip. Do not attempt real feature extraction on the ESP32 – leave that to the phone. Time spent making the ESP32 ”smart” is time not spent on getting the demo end-to-end.

5. Package a compact struct/JSON packet and push it over BLE (GATT characteristic, notify-on-change) every 1 second or so at minimum for the fast sensors; slow sensors can piggyback less frequently.

P2

- Buffer a few seconds of data locally on the ESP32 if BLE briefly disconnects, so you don’t lose data on every minor connection drop.
- Add a status LED / buzzer driven by ESP32 GPIO for a simple physical ”connected/alert” indicator – cheap, and looks great in a live demo.

[STRETCH – CUT FIRST]

Haptic feedback motor, onboard actuator control, full local SOS logic on the ESP32 itself. Your PPT already shows these as part of the long-term vision – do not build them now.

### 2.4 First 4 Hours -- Your Concrete Checklist

1. Get any single sensor (start with MPU6050, it’s the easiest to verify) reading values over serial monitor.
2. Get ESP32 broadcasting a BLE GATT service with a dummy/fake value, and confirm the mobile app person can actually connect and read it. This unblocks the whole team and should happen before real sensor integration is finished.
3. Only after that handshake works, wire in ECG, then ambient sensors, in that order.

## 3 AI / Edge AI Person -- Signal Processing, Models & Personalization

Your Mission

Turn the raw sensor stream coming off the ESP32 into decisions a human can act on: ”this heart rhythm looks abnormal,” ”heat stress risk is high,” ”this looks like a fall.” In 48 hours, ”AI” mostly means welldesigned signal processing plus transparent rule/statistical logic, not trained neural networks – and that is the right, honest choice, not a compromise. This is the section your team should spend the most relative time on, since it is your product’s central differentiator.

Where Inference Actually Runs -- Be Honest About This

The PPT says ”on-device AI” and ”TensorFlow Lite” – that claim should refer to inference happening on the phone, not the ESP32. The ESP32 (typically 240MHz, no dedicated NN accelerator) cannot realistically run a TFLite model in your timeframe, and attempting it will burn a day you don’t have. The correct, still fully truthful architecture is: ESP32 acquires and lightly filters → phone runs the actual inference/rules via TFLite or plain on-device code. This matches ”on-device” (nothing leaves the phone to a cloud server) and is what ”edge AI” means in almost every real wearable product today.

### 3.1 The Signal Chain (Do This in Order)

P1 -- ECG Preprocessing Pipeline

1. Notch filter at 50 Hz to remove Indian AC powerline interference – this is close to mandatory for any ECG signal collected indoors in India, and it’s a small, well-known filter (IIR notch, narrow bandwidth around 50 Hz).
2. Bandpass filter roughly 0.5–40 Hz to remove baseline wander (low frequency drift from breathing/movement) and high-frequency EMG/muscle noise, while preserving the actual QRS complex shape.
3. R-peak detection using a simple threshold-and-refractory-period approach (a lightweight Pan-Tompkins-style method is the standard, well-documented choice: differentiate → square → movingwindow integrate → adaptive threshold). This gives you beat-to-beat R-R intervals.
4. Heart rate = 60 / (average R-R interval in seconds) over a rolling window.
5. HRV / rhythm irregularity = variance or standard deviation of R-R intervals over the last N beats. A sudden spike in this variance, or R-R intervals far outside the person’s own recent baseline, is your ”possible arrhythmia” flag – not a diagnosis, frame it as a risk flag only.
6. Motion-artifact gating: use the MPU6050 stream to detect when the person is moving heavily, and suppress/down-weight ECG-based alerts during those windows since motion is the single biggest source of false alarms in wearable ECG.

### 3.2 The Four Detection Models -- Realistic 48-Hour Versions

Model | 48-hour realistic approach | Priority
Heart Health | Rolling baseline HR + R-R variance per user; flag when current reading deviates beyond a threshold (e.g., 2 standard de-viations) from their own recent baseline, gated by motion state | [P1 – MUST HAVE]
Heat Stress | Compute a heat index from ambient tem-perature + humidity using the standard heat-index formula (Rothfusz regression, the same approach meteorological ser-vices use), combine with elevated HR to raise confidence | [P1 – MUST HAVE]
Fall Detection | Accelerometer magnitude pattern: near-zero-g free-fall dip → sharp impact spike → sustained stillness after impact. This threshold-sequence approach is the stan-dard lightweight fall-detection method used in real wearables | [P2 – HIGH VALUE]
Respiratory Risk | Combine ambient AQI/MQ135 reading with any available breathing-rate proxy (chest motion cycle from accelerometer, if time allows) or simply AQI thresholds + person’s risk profile (elderly/chronic con-dition flag they set in-app) | [P2 – HIGH VALUE]

[STRETCH – CUT FIRST]

A trained CNN arrhythmia classifier on MIT-BIH data (as your PPT lists under future scope) needs a labeled dataset, training time, and quantization/conversion to TFLite – this is a multi-week effort done properly, not a 48-hour one. State it as future scope exactly as your deck already does; do not attempt a rushed version, since a broken ”AI model” is worse for the demo than an honest, well-explained rule engine.

### 3.3 Personalization -- What's Actually Buildable

P2

Maintain a simple rolling per-user baseline: for each metric (resting HR, typical R-R variance, typical activity level), keep a moving average over the last 3–7 days of data (or last N sessions if you don’t have days). Compare live readings against that person’s baseline rather than a fixed population threshold. This is honest, explainable ”personalization” – it is not machine learning in the training sense, and that’s fine to say plainly: it’s adaptive thresholding, and it’s exactly the right amount of sophistication for this timeframe.

### 3.4 Fusing In External Context (Open APIs)

P1

When the phone has connectivity, pull local weather + AQI from a free public API (e.g., OpenWeatherMap or the Indian government’s AQI data sources) using the phone’s GPS location, and use that alongside/as a fallback for the on-garment MQ135 and ambient temperature sensors. This lets your heat-stress and respiratory-risk models work even before the hardware sensors are fully calibrated, and gives you a fallback if a hardware sensor is flaky on demo day.

P2

When offline, fall back entirely to on-garment ambient sensor readings for heat/AQI context – this is the actual point of your product’s ”works without internet” claim, so make sure this fallback path is demoed, not just the online path.

### 3.5 Your First 4 Hours

1. Get a fake/simulated ECG waveform (a public sample, or a simple synthetic sine + noise) flowing through your notch → bandpass → R-peak pipeline in a notebook/script, completely independent of hardware.
2. Confirm HR and HRV numbers come out sane on that fake data.
3. As soon as the hardware person has any real ECG samples coming off the ESP32 (even noisy), swap your fake data source for the real one – don’t wait for ”clean” hardware data before integrating.

## 4 Mobile App Team (2 People) -- Feature Ownership & Priority

Your Mission

Two of you own the entire phone app: receiving the BLE stream, running/consuming the AI person’s logic, showing a dashboard, and handling alerts + SOS. Split the work by surface so you don’t collide on the same files: one person owns the data/connectivity core, the other owns alerts, integrations, and outward-facing UI polish.

### 4.1 Suggested Split

Person A – Core & Data | Person
BLE connection to ESP32, receiving/parsing live sensor packets, wiring received data into local storage, live vitals dashboard screen | Weather/AQI

### 4.2 Prioritized Feature List

P1 -- Both People -- First 12 Hours

- BLE scan + connect to the ESP32’s GATT service, and reliably re-parse its data packets (Person A)
- A single ”Live Vitals” screen showing HR, SpO2, ambient temp, AQI, and a basic status indicator (Normal / Caution / Risk) – this is the single most important screen in the whole product for a live demo

(Person A)

- Local storage write-path: every incoming reading gets saved (hand off to Database person’s schema) (Person A)
- Basic alert banner/notification when the AI layer flags a risk (e.g., ”High Heat Alert – 42°C, stay hydrated”) (Person B)
- Weather/AQI API call using phone GPS, displayed alongside on-device readings (Person B)

P2 -- Next 12 Hours

- Trend view / simple history graph for HR and heat-risk over the last few hours (Person A)
- SOS button: on tap, send an SMS (using the phone’s native SMS capability, no internet required) to a pre-set emergency contact with a canned message + last known location if permission granted (Person B)
- ”Disconnected / working offline” indicator so it’s visually obvious the app still functions without internet during the demo (Person B)
- Fall-detected alert with a countdown-to-auto-SOS behavior (cancel within N seconds if it was a false alarm) (Person B)

P3 -- Only If P1/P2 Done Across Whole Team

- Risk score visualizations per category (heat/AQI/flood/storm) matching the PPT’s dashboard mockup styling
- Recent alerts/updates feed / history log screen
- Basic user profile with vulnerability flags (elderly, chronic condition) that feed into the AI person’s risk thresholds

[STRETCH – CUT FIRST]

Caregiver/family dashboard view, multi-user accounts, regional-language voice alerts – explicitly future scope per your own deck. Do not touch these in 48 hours.

### 4.3 Practical Notes

- Do not wait for real hardware to start the BLE integration – ask the hardware person for a dummy/fake BLE service emitting hardcoded values on hour 1–2, and build against that. Swap in the real stream later; the app-side code barely changes.
- Do not wait for the AI person’s final logic to build the alert UI – build the alert banner against a hardcoded/mock ”risk level” value first, then wire the real AI output in once it exists.
- Keep the dashboard visually close to what’s already in the PPT mockup (the frontend person owns final polish, but structurally match it early so integration is trivial later).

## 5 Database / Data Layer Person

Your Mission

Decide where every reading, alert, and user setting lives, and make sure the mobile team can write to and read from it without friction. Given this product’s entire pitch is privacy-preserving and offline-first, your default should be an on-device data layer, not a cloud database.

Reality Check on InfluxDB / Cloud Options

A dedicated time-series database like InfluxDB is built for server-side, networked deployments – it doesn’t meaningfully run ”on-device” inside a phone app in the way this product needs, and standing up a cloud instance directly contradicts the ”nothing sent to the cloud” claim that is your product’s core differentiator versus the cloud-based competitors in your own comparison slide. Unless the team explicitly wants an optional caregiver-sync feature (P3 at best), skip cloud databases entirely and keep everything local.

### 5.1 Recommended Setup

P1

- SQLite (via Room, since the app is likely React Native/Android – coordinate the exact binding library with the mobile team) as the single on-device store for all time-series-like readings (HR, SpO2, temp, AQI, motion events) and for alerts/events history.
- Design tables around: readings (timestamp, sensor_type, value, source=[garment/api]), alerts (timestamp, category, severity, message, acknowledged), user_profile (baseline values, vulnerability flags, emergency contact).
- Index on timestamp for fast ”last N minutes” queries – this is what the live dashboard and trend graphs will hit constantly.

P2

- A simple rolling-baseline table that the AI person’s personalization logic reads/writes (per-metric moving average, updated on a schedule) – this is the concrete data-layer piece the AI person’s P2 feature depends on, so prioritize this once P1 is done.
- Basic data retention/pruning (e.g., keep raw readings for 7 days, keep daily summaries indefinitely) so the local DB doesn’t bloat during long demo/testing sessions.

[STRETCH – CUT FIRST]

Optional cloud sync for a caregiver dashboard, multi-device sync, InfluxDB/Firebase cloud backend. Mention in PPT as a scalability future step (your deck’s ”Firebase” tech stack entry is fine to keep as a stated future option) – do not build during the hackathon.

### 5.2 Your First 4 Hours

1. Agree the exact schema (field names, types) with both mobile app people before anyone writes code against it – this single conversation prevents the most common last-minute integration breakage.
2. Stand up the SQLite tables with a few rows of dummy data so Person A (mobile) can build the dashboard’s read-path immediately, in parallel with real data flowing in.

## 6 Frontend Design + PPT/Demo Person

Your Mission

You own two things: the app’s visual polish (working closely with both mobile devs so their screens actually match the PPT’s mockup aesthetic) and the pitch itself – slides plus, critically, the live demo script. In a hackathon, a confident, well-paced demo usually matters more than any single slide.

### 6.1 What's Already Strong in Your Existing Deck

- The problem framing with concrete stats (554 heatwave days, 75% outdoor workforce, rural vs urban internet gap) is compelling and specific – keep it.
- The competitor comparison table (fitness bands vs premium wearables vs cloud apps) is a strong, clear differentiation device – keep it front and center.
- The ”Future Scope & Limitations” slide being explicit and honest is a real strength; judges respond well to teams that know their own limits.

### 6.2 P1 -- What to Build/Polish First

P1

- A tight, rehearsed live demo script: exact sequence of taps/actions that shows (a) live vitals updating from the actual garment, (b) a heat or fall alert firing, (c) the offline SOS path, in under 90 seconds. Write this script down and rehearse it with whoever is presenting – this matters more than any slide.
- Make sure the actual app UI matches your mockup’s visual language (colors, card layout, iconography) closely enough that switching between slides and the live app doesn’t feel jarring.

P2

- Update the technical architecture slide to reflect the honest split of where processing happens (ESP32 = acquisition/filtering, phone = actual AI/decisions) – this avoids a judge catching an inconsistency between the slide and a technical Q&A answer.
- Prepare 2–3 backup slides/screenshots of the app in case a live BLE demo fails on stage (a very common hackathon failure mode) – have a recorded video or screenshots as fallback.

Backup Plan Is Not Optional

Live hardware demos fail at hackathons more often than they succeed, usually due to BLE pairing issues under stage conditions (RF interference from other teams’ devices). Record a clean video of the full flow working on hour 40ish, regardless of confidence in the live version, and have it ready to play if needed.

### 6.3 Your First 4 Hours

1. Confirm the exact list of P1 features across all roles (from this document) so your demo script is scoped to what will actually exist, not what’s aspirational.
2. Start drafting the demo script now, even against mocked/fake data – refine it as real features land instead of writing it cold on the last day.

## 7 48-Hour Master Timeline

Time | Milestone (whole team)
Hour 0–4 | Everyone sets up their own tooling in parallel. Hardware: single sensor reading over serial. Mobile: fake BLE service connects to app. DB: schema agreed and stubbed. AI: fake-data signal pipeline runs. Frontend: demo script skeleton drafted.
Hour 4–12 | First real end-to-end data flow: real (even if noisy) ESP32 data → phone → dashboard showing something live. All P1 features across roles actively in progress.
Hour 12–24 | P1 features across every role complete and integrated together. First full run-through of the demo script, even if rough.
Hour 24–36 | P2 features layered in: alerts firing off real logic, SOS working, personal-ization baseline running, dashboard visuals polished to match mockups.
Hour 36–44 | Stop building new features. Focus entirely on integration bugs, edge cases in the demo path, and rehearsing the pitch. Record the backup demo video now.
Hour 44–48 | Final rehearsal, slides finalized, everyone sleeps at least a little before pre-senting.

Final Word

Every role in this document has been scoped to what is genuinely buildable by one or two people in 48 hours, using well-established, real techniques (Pan-Tompkins-style R-peak detection, standard heat-index formulas, threshold-based fall detection, rolling-baseline personalization) rather than anything that requires training data or weeks of tuning. If a judge asks ”is this really AI,” the honest and correct answer is: ”it’s signal-processing-driven risk detection with adaptive personal baselines, running fully on-device – with trained deep learning models as an explicit next step,” and that is a strong, technically credible answer.

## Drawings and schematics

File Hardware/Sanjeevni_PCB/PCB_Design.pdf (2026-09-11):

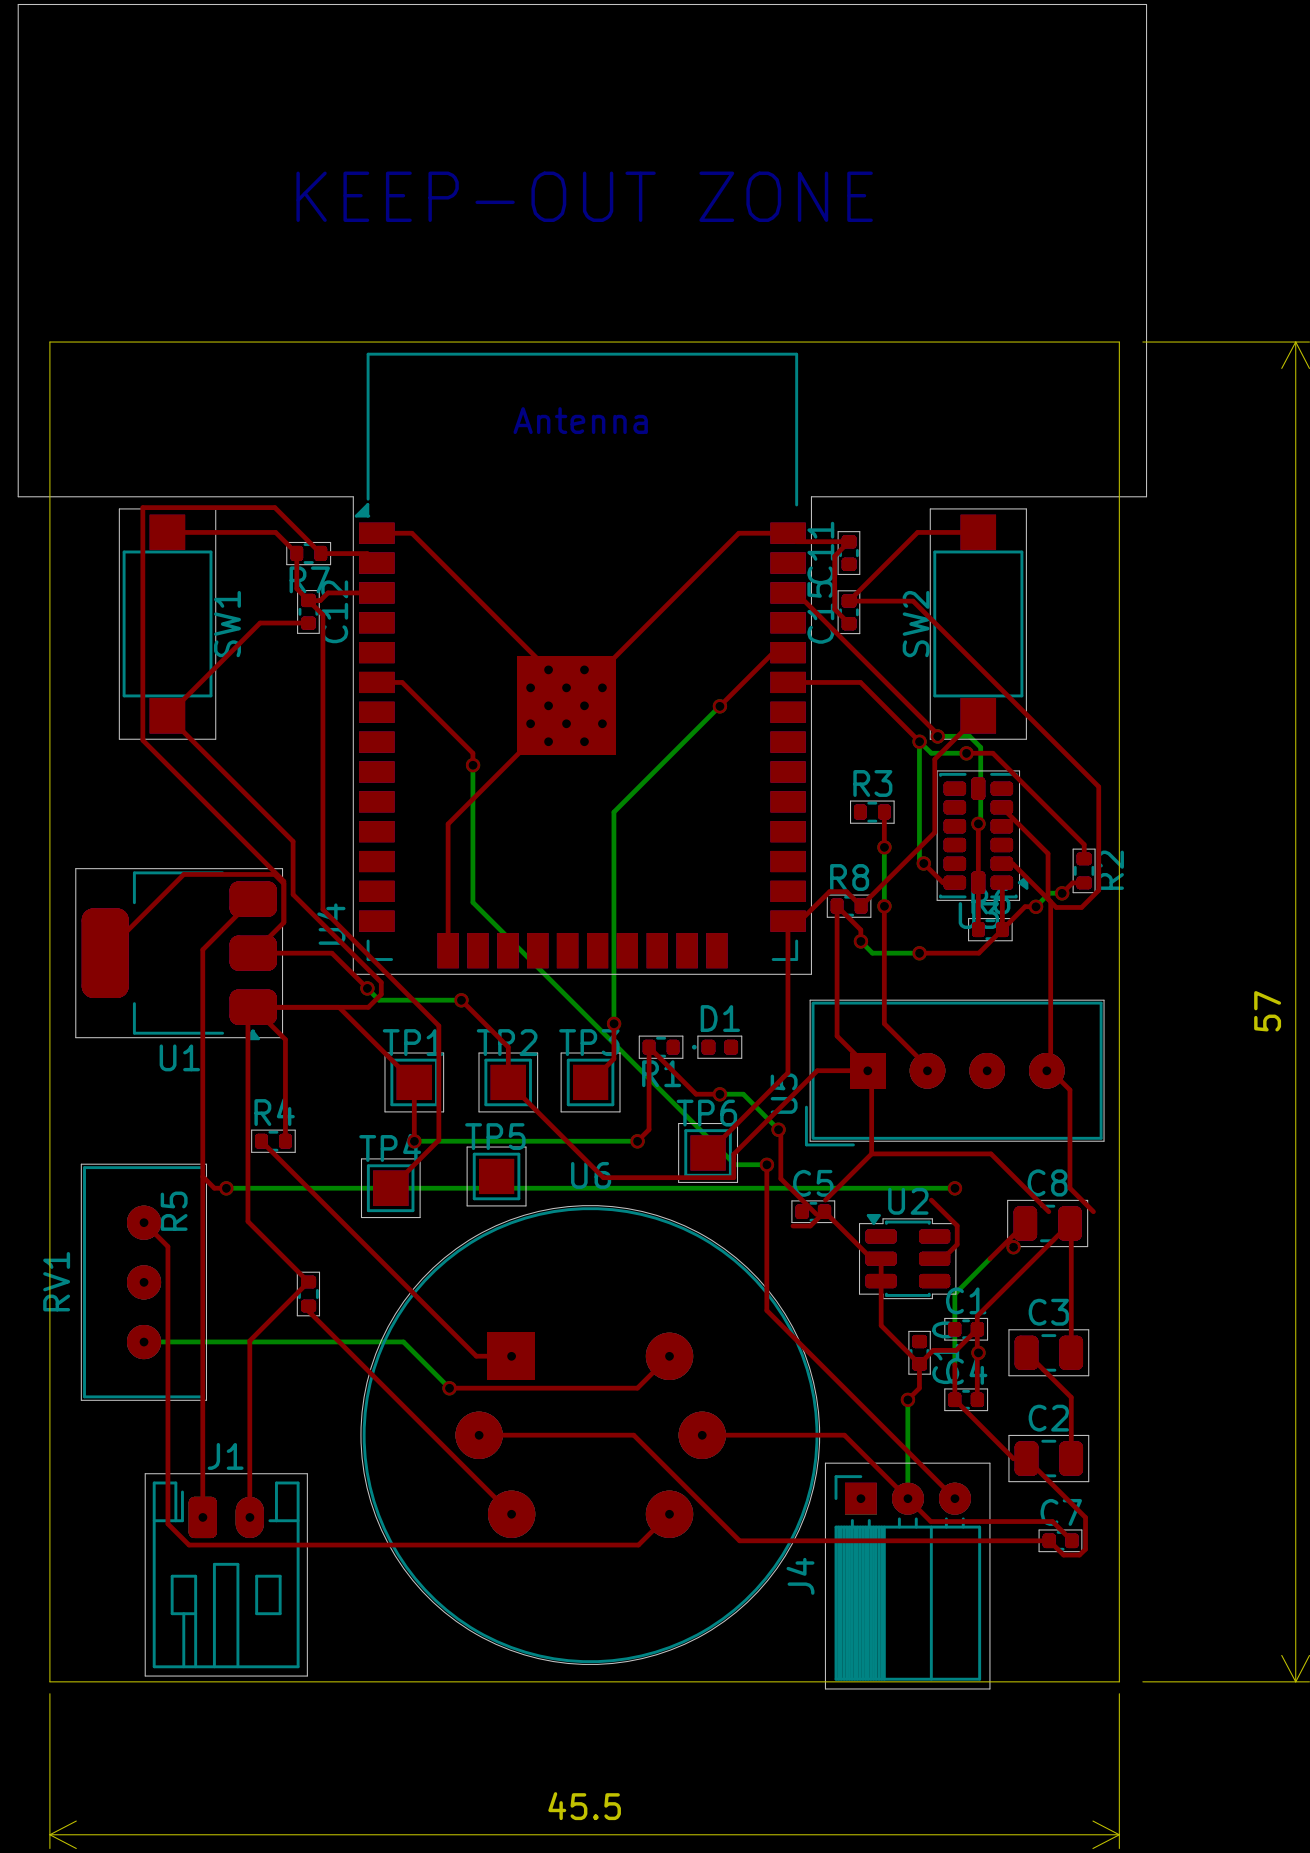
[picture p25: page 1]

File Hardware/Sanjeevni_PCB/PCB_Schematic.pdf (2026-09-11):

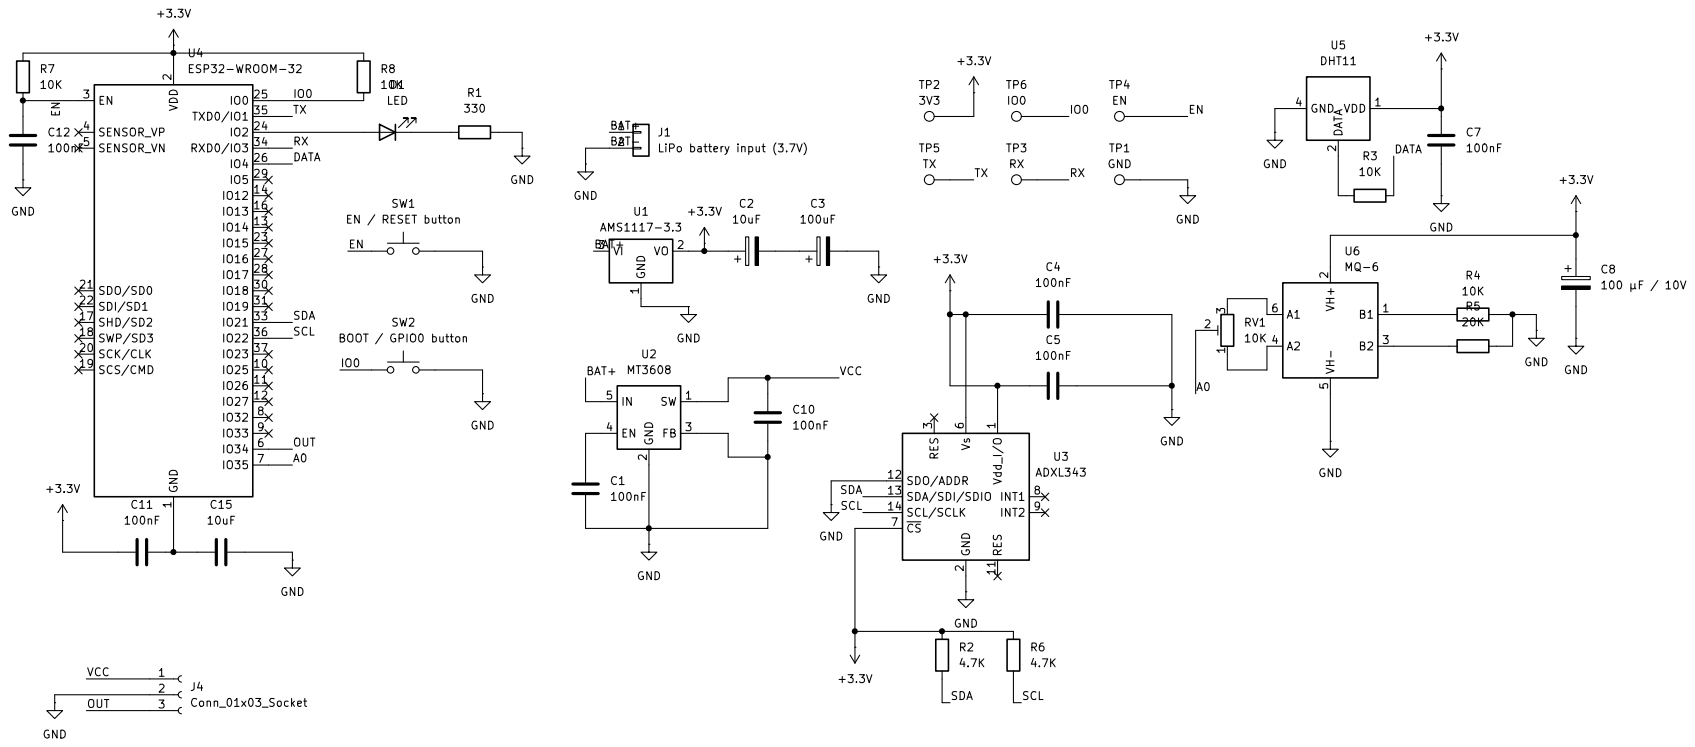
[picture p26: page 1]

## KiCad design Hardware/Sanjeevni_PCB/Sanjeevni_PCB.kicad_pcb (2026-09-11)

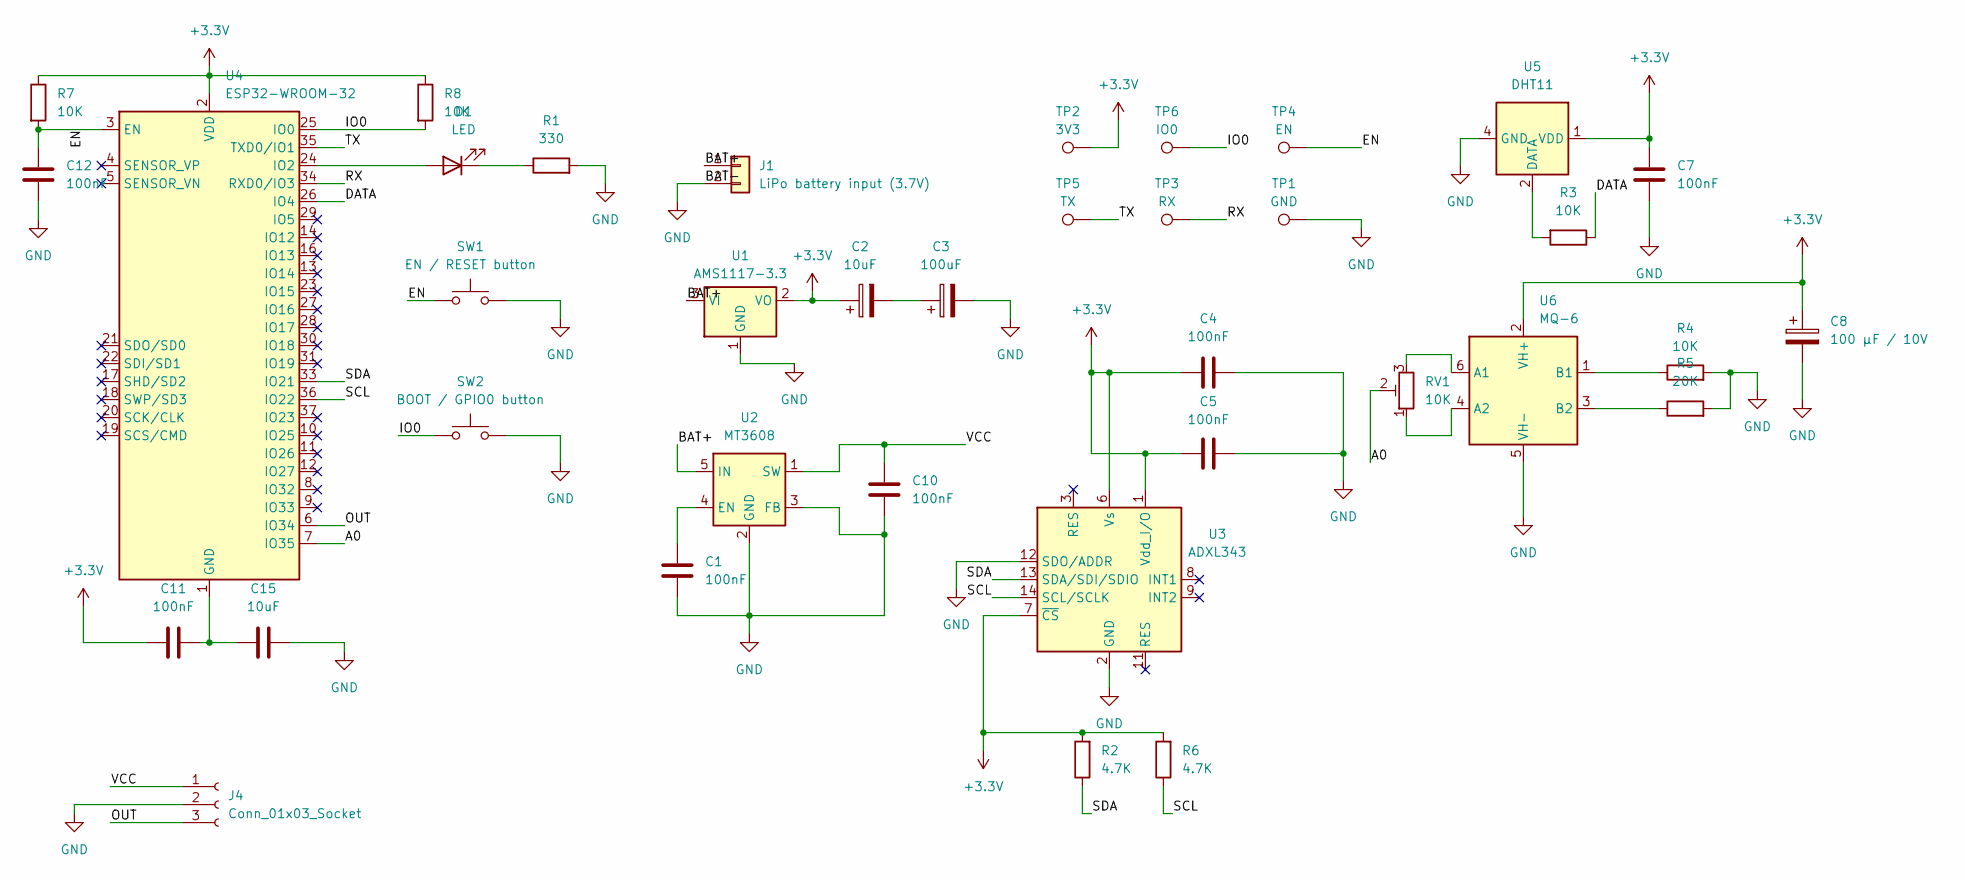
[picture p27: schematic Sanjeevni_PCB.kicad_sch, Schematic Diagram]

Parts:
C1, C4, C5, C7, C10, C11, C12: 100nF; C_0402_1005Metric
C2: 10uF; C_0805_2012Metric
C3: 100uF; C_0805_2012Metric
C8: 100 µF / 10V; C_0805_2012Metric
C15: 10uF; C_0402_1005Metric
D1: LED; LED_0402_1005Metric
J1: LiPo battery input (3.7V); JST_PH_S2B-PH-K_1x02_P2.00mm_Horizontal
J4: Conn_01x03_Socket; PinSocket_1x03_P2.00mm_Horizontal
R1: 330; R_0402_1005Metric
R2, R6: 4.7K; R_0402_1005Metric
R3, R4, R7, R8: 10K; R_0402_1005Metric
R5: 20K; R_0402_1005Metric
RV1: 10K; Potentiometer_Bourns_3296W_Vertical
SW1: EN / RESET button; SW_SPST_CK_RS282G05A3
SW2: BOOT / GPIO0 button; SW_SPST_CK_RS282G05A3
TP1: GND; TestPoint_Pad_1.5x1.5mm
TP2: 3V3; TestPoint_Pad_1.5x1.5mm
TP3: RX; TestPoint_Pad_1.5x1.5mm
TP4: EN; TestPoint_Pad_1.5x1.5mm
TP5: TX; TestPoint_Pad_1.5x1.5mm
TP6: IO0; TestPoint_Pad_1.5x1.5mm
U1: AMS1117-3.3; SOT-223-3_TabPin2
U2: MT3608; SOT-23-6
U3: ADXL343; LGA-14_3x5mm_P0.8mm_LayoutBorder1x6y
U4: ESP32-WROOM-32
U5: DHT11; Aosong_DHT11_5.5x12.0_P2.54mm
U6: MQ-6

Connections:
+3.3V: C2.1, C4.1, C5.1, C7.1, C8.1, C11.1, R2.2, R6.2, R7.1, R8.1, TP2.1 (1_1), U1.2 (VO), U3.1 (Vdd_I/O), U3.6 (Vs), U3.7 (~CS), U4.2 (VDD), U5.1 (VDD), U6.2 (VH+)
/A0: RV1.2, U4.7 (IO35)
/BAT+: J1.1, U1.3 (VI), U2.5 (IN)
/DATA: R3.1, U4.26 (IO4)
/EN: C12.1, R7.2, SW1.1, TP4.1 (1_1), U4.3 (EN)
/IO0: R8.2, SW2.1, TP6.1 (1_1), U4.25 (IO0)
/OUT: J4.3, U4.6 (IO34)
/RX: TP3.1 (1_1), U4.34 (RXD0/IO3)
/SCL: R6.1, U3.14 (SCL/SCLK), U4.36 (IO22)
/SDA: R2.1, U3.13 (SDA/SDI/SDIO), U4.33 (IO21)
/TX: TP5.1 (1_1), U4.35 (TXD0/IO1)
/VCC: C10.1, J4.1, U2.1 (SW)
GND: C1.2, C3.2, C4.2, C5.2, C7.2, C8.2, C10.2, C12.2, C15.2, J1.2, J4.2, R1.2, R4.2, R5.2, SW1.2, SW2.2, TP1.1 (1_1), U1.1 (GND), U2.2 (GND), U2.3 (FB), U3.2 (GND), U3.4 (GND), U3.5 (GND), U3.12 (SDO/ADDR), U5.4 (GND), U6.5 (VH-)
unnamed: C2.2, C3.1
unnamed: C11.2, C15.1, U4.1 (GND), U4.15 (GND), U4.38 (GND), U4.39 (GND)
unnamed: D1.2 (A), U4.24 (IO2)
unnamed: D1.1 (K), R1.1
unnamed: C1.1, U2.4 (EN)
unnamed: R3.2, U5.2 (DATA)
unnamed: RV1.3, U6.6 (A1)
unnamed: RV1.1, U6.4 (A2)
unnamed: R4.1, U6.1 (B1)
unnamed: R5.1, U6.3 (B2)

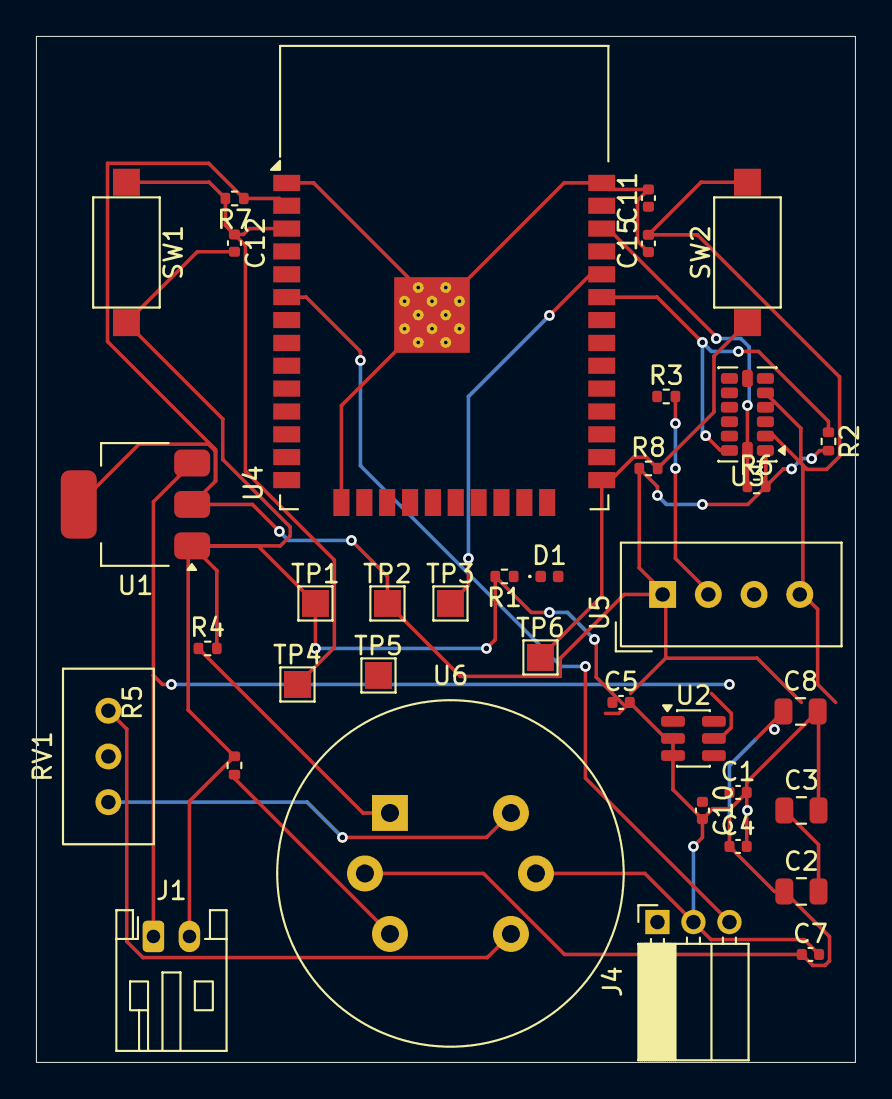
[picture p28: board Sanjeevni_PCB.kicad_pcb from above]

Board: 2 copper layers, 45.5 x 57.0 mm, 37 parts (0 on the bottom side), 23 nets.

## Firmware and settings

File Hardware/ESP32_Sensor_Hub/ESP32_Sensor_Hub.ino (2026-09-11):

// =============================================================================
// ESP32_Sensor_Hub.ino
//
// Single-file integration for:
//   - BioAmp EXG Pill  (Sensor ID 1) — GPIO 34, 500 Hz, 128-sample buffer
//   - ADXL345           (Sensor ID 2) — I2C SDA=21/SCL=22, 100 Hz acq / 25 Hz BLE
//   - DHT11             (Sensor ID 3) — GPIO 4, 0.5 Hz
//   - MQ135             (Sensor ID 4) — GPIO 35, 10 Hz acq / 1 Hz BLE
//   - Soil Moisture     (Sensor ID 5) — GPIO 32, 10 Hz acq / 0.5 Hz BLE
//
// Transport : Bluetooth Low Energy (BLE) GATT Server — Nordic UART Service (NUS)
// Format    : Compact JSON, newline-delimited
// Timestamp : ESP32 uptime via millis() — NOT a Unix wall-clock timestamp
// Protocol  : version 1 ("v":1)
//
// Board target : Classic ESP32 (ESP32-WROOM / DevKit V1), ESP32-S3, ESP32-C3
// Arduino framework
// =============================================================================

// ─────────────────────────────────────────────
// 1. INCLUDES
// ─────────────────────────────────────────────
#include <Arduino.h>
#include <BLEDevice.h>          // BLE Core
#include <BLEServer.h>          // BLE GATT Server
#include <BLEUtils.h>           // BLE Utilities
#include <BLE2902.h>            // BLE CCCD Descriptor for Notifications
#include <Wire.h>               // I2C for ADXL345
#include <Adafruit_Sensor.h>    // Adafruit unified sensor abstraction
#include <Adafruit_ADXL345_U.h> // ADXL345 driver
#include <DHT.h>                // DHT sensor library (Adafruit)
#include <ArduinoJson.h>        // JSON serialisation

// ─────────────────────────────────────────────
// 2. PIN CONFIGURATION  (edit here only)
// ─────────────────────────────────────────────
#define PIN_EXG 34     // BioAmp EXG Pill — analog input (input-only GPIO)
#define PIN_I2C_SDA 21 // ADXL345 SDA
#define PIN_I2C_SCL 22 // ADXL345 SCL
#define PIN_DHT 4      // DHT11 data
#define PIN_MQ135 35   // MQ135 analog out (input-only GPIO)
#define PIN_SOIL 32    // Soil moisture analog out

// ─────────────────────────────────────────────
// 3. CONSTANTS & BLE UUIDs
// ─────────────────────────────────────────────

// EXG
static const uint16_t EXG_SAMPLE_RATE_HZ = 500;
static const uint16_t EXG_BUFFER_SIZE = 128;
static const uint32_t EXG_INTERVAL_US = 1000000UL / EXG_SAMPLE_RATE_HZ; // 2000 us

// ADXL345
static const uint32_t ADXL_ACQ_INTERVAL_MS = 10; // 100 Hz acquisition
static const uint32_t ADXL_TX_INTERVAL_MS = 40;  // 25 Hz BLE transmission

// DHT11
static const uint32_t DHT_INTERVAL_MS = 2000; // 0.5 Hz

// MQ135
static const uint32_t MQ135_ACQ_INTERVAL_MS = 100; // 10 Hz acquisition
static const uint32_t MQ135_TX_INTERVAL_MS = 1000; // 1 Hz BLE transmission
static const uint8_t MQ135_AVG_SAMPLES = 10;       // averaging window

// Soil moisture
static const uint32_t SOIL_ACQ_INTERVAL_MS = 100; // 10 Hz acquisition
static const uint32_t SOIL_TX_INTERVAL_MS = 2000; // 0.5 Hz BLE transmission
static const uint8_t SOIL_AVG_SAMPLES = 10;       // averaging window

// DHT sensor type
#define DHT_TYPE DHT11

// BLE Device Name
#define BLE_DEVICE_NAME "ESP32_SENSOR_HUB_BLE"

// Nordic UART Service (NUS) UUIDs
#define SERVICE_UUID "6E400001-B5A3-F393-E0A9-E50E24DCCA9E"
#define CHARACTERISTIC_UUID_RX "6E400002-B5A3-F393-E0A9-E50E24DCCA9E"
#define CHARACTERISTIC_UUID_TX "6E400003-B5A3-F393-E0A9-E50E24DCCA9E"

// ─────────────────────────────────────────────
// 4. SENSOR ID ENUM  (protocol-defined — do NOT change numeric values)
// ─────────────────────────────────────────────
enum class SensorId : uint8_t
{
    EXG = 1,
    ADXL345 = 2,
    DHT11 = 3,
    MQ135 = 4,
    SOIL_MOISTURE = 5
};

// ─────────────────────────────────────────────
// 5. GLOBAL SENSOR & BLE OBJECTS
// ─────────────────────────────────────────────

BLEServer *pServer = nullptr;
BLECharacteristic *pTxCharacteristic = nullptr;
bool deviceConnected = false;
bool oldDeviceConnected = false;

Adafruit_ADXL345_Unified adxl = Adafruit_ADXL345_Unified(12345);
DHT dht(PIN_DHT, DHT_TYPE);

// Sensor availability flags
bool adxlAvailable = false;

// Per-sensor sequence counters (independent tracking)
uint32_t exgSequence = 0;
uint32_t adxlSequence = 0;
uint32_t dhtSequence = 0;
uint32_t mq135Sequence = 0;
uint32_t soilSequence = 0;

// ─────────────────────────────────────────────
// 6. EXG BUFFER & SENSOR STATE
// ─────────────────────────────────────────────
uint16_t exgBuffer[EXG_BUFFER_SIZE];
uint16_t exgBufferIndex = 0;
uint32_t exgLastMicros = 0;

// ADXL345 State
uint32_t adxlLastAcqMs = 0;
uint32_t adxlLastTxMs = 0;
float adxlX = 0.0f, adxlY = 0.0f, adxlZ = 0.0f;

// DHT11 State
uint32_t dhtLastMs = 0;

// MQ135 State
uint32_t mq135LastAcqMs = 0;
uint32_t mq135LastTxMs = 0;
uint32_t mq135AccumRaw = 0;
uint8_t mq135SampleCnt = 0;
uint32_t mq135AvgRaw = 0;

// Soil Moisture State
uint32_t soilLastAcqMs = 0;
uint32_t soilLastTxMs = 0;
uint32_t soilAccumRaw = 0;
uint8_t soilSampleCnt = 0;
uint32_t soilAvgRaw = 0;

// ─────────────────────────────────────────────
// 7. BLE SERVER CALLBACKS
// ─────────────────────────────────────────────
class HubServerCallbacks : public BLEServerCallbacks
{
    void onConnect(BLEServer *pServer) override
    {
        deviceConnected = true;
        Serial.println("[BLE] Central client connected!");
    }

    void onDisconnect(BLEServer *pServer) override
    {
        deviceConnected = false;
        Serial.println("[BLE] Central client disconnected!");
    }
};

// =============================================================================
// 8. SENSOR INITIALIZATION FUNCTIONS
// =============================================================================

void setupEXG()
{
    pinMode(PIN_EXG, INPUT);
    exgLastMicros = micros();
    exgBufferIndex = 0;
    Serial.println("[EXG]  Initialized — GPIO 34 | 500 Hz | 128-sample buffer");
}

void setupADXL345()
{
    Wire.begin(PIN_I2C_SDA, PIN_I2C_SCL);

    if (!adxl.begin())
    {
        Serial.println("[ADXL345] ERROR — sensor not detected on I2C bus. Continuing without ADXL345.");
        adxlAvailable = false;
        return;
    }

    adxl.setRange(ADXL345_RANGE_2_G);
    adxlAvailable = true;
    adxlLastAcqMs = millis();
    adxlLastTxMs = millis();
    Serial.println("[ADXL345] Initialized — SDA=21, SCL=22 | 2G range | 100 Hz acq / 25 Hz BLE");
}

void setupDHT()
{
    dht.begin();
    dhtLastMs = millis();
    Serial.println("[DHT11] Initialized — GPIO 4 | 0.5 Hz");
}

void setupMQ135()
{
    analogSetPinAttenuation(PIN_MQ135, ADC_11db); // 0–3.3 V input range
    pinMode(PIN_MQ135, INPUT);
    mq135LastAcqMs = millis();
    mq135LastTxMs = millis();
    Serial.println("[MQ135] Initialized — GPIO 35 | raw ADC | 10 Hz acq / 1 Hz BLE");
}

void setupSoilMoisture()
{
    analogSetPinAttenuation(PIN_SOIL, ADC_11db);
    pinMode(PIN_SOIL, INPUT);
    soilLastAcqMs = millis();
    soilLastTxMs = millis();
    Serial.println("[SOIL]  Initialized — GPIO 32 | raw ADC | 10 Hz acq / 0.5 Hz BLE");
}

void setupBLE()
{
    BLEDevice::init(BLE_DEVICE_NAME);
    BLEDevice::setMTU(517); // Request maximum MTU for high-throughput packets

    pServer = BLEDevice::createServer();
    pServer->setCallbacks(new HubServerCallbacks());

    BLEService *pService = pServer->createService(SERVICE_UUID);

    pTxCharacteristic = pService->createCharacteristic(
        CHARACTERISTIC_UUID_TX,
        BLECharacteristic::PROPERTY_NOTIFY);
    pTxCharacteristic->addDescriptor(new BLE2902());

    BLECharacteristic *pRxCharacteristic = pService->createCharacteristic(
        CHARACTERISTIC_UUID_RX,
        BLECharacteristic::PROPERTY_WRITE);

    pService->start();

    BLEAdvertising *pAdvertising = BLEDevice::getAdvertising();
    pAdvertising->addServiceUUID(SERVICE_UUID);
    pAdvertising->setScanResponse(true);
    pAdvertising->setMinPreferred(0x06);
    pAdvertising->setMinPreferred(0x12);
    BLEDevice::startAdvertising();

    Serial.printf("[BLE]  GATT Server ready as '%s'\n", BLE_DEVICE_NAME);
}

// =============================================================================
// 9. SENSOR ACQUISITION FUNCTIONS
// =============================================================================

// readEXG() — non-blocking micros()-based 500 Hz scheduler.
// Returns true ONLY when the 128-sample buffer is full and ready to send.
bool readEXG()
{
    uint32_t now = micros();

    if ((now - exgLastMicros) < EXG_INTERVAL_US)
        return false;

    // Advance reference by fixed interval to avoid drift accumulation
    exgLastMicros += EXG_INTERVAL_US;

    exgBuffer[exgBufferIndex++] = (uint16_t)analogRead(PIN_EXG);

    if (exgBufferIndex >= EXG_BUFFER_SIZE)
    {
        exgBufferIndex = 0;
        return true;
    }
    return false;
}

// readADXL345() — acquires at 100 Hz; stores latest reading in adxlX/Y/Z.
bool readADXL345()
{
    if (!adxlAvailable)
        return false;

    uint32_t now = millis();
    if ((now - adxlLastAcqMs) < ADXL_ACQ_INTERVAL_MS)
        return false;
    adxlLastAcqMs = now;

    sensors_event_t event;
    adxl.getEvent(&event);
    adxlX = event.acceleration.x;
    adxlY = event.acceleration.y;
    adxlZ = event.acceleration.z;
    return true;
}

// readDHT() — reads at 0.5 Hz; validates with isnan().
bool readDHT(float &temperature, float &humidity)
{
    uint32_t now = millis();
    if ((now - dhtLastMs) < DHT_INTERVAL_MS)
        return false;
    dhtLastMs = now;

    float t = dht.readTemperature();
    float h = dht.readHumidity();

    if (isnan(t) || isnan(h))
    {
        Serial.println("[DHT11] ERROR — read returned NaN. Skipping this packet.");
        return false;
    }

    temperature = t;
    humidity = h;
    return true;
}

// readMQ135() — acquires at 10 Hz; averages every 10 samples.
bool readMQ135()
{
    uint32_t now = millis();
    if ((now - mq135LastAcqMs) < MQ135_ACQ_INTERVAL_MS)
        return false;
    mq135LastAcqMs = now;

    mq135AccumRaw += (uint32_t)analogRead(PIN_MQ135);
    mq135SampleCnt++;

    if (mq135SampleCnt >= MQ135_AVG_SAMPLES)
    {
        mq135AvgRaw = mq135AccumRaw / (uint32_t)MQ135_AVG_SAMPLES;
        mq135AccumRaw = 0;
        mq135SampleCnt = 0;
        return true;
    }
    return false;
}

// readSoilMoisture() — acquires at 10 Hz; averages every 10 samples.
bool readSoilMoisture()
{
    uint32_t now = millis();
    if ((now - soilLastAcqMs) < SOIL_ACQ_INTERVAL_MS)
        return false;
    soilLastAcqMs = now;

    soilAccumRaw += (uint32_t)analogRead(PIN_SOIL);
    soilSampleCnt++;

    if (soilSampleCnt >= SOIL_AVG_SAMPLES)
    {
        soilAvgRaw = soilAccumRaw / (uint32_t)SOIL_AVG_SAMPLES;
        soilAccumRaw = 0;
        soilSampleCnt = 0;
        return true;
    }
    return false;
}

// =============================================================================
// 10. JSON / BLE TRANSMISSION FUNCTIONS
// =============================================================================

// Internal helper — serialises doc and streams out over BLE notifications.
// Employs a safe 128-byte chunker to guarantee delivery across all BLE clients.
static void sendJson(JsonDocument &doc)
{
    if (!deviceConnected)
        return;

    String output;
    output.reserve(1600);
    serializeJson(doc, output);
    output += '\n';

    const uint8_t *data = (const uint8_t *)output.c_str();
    size_t len = output.length();
    size_t offset = 0;
    const size_t maxChunk = 128; // Safe packet size for negotiated MTU

    while (offset < len)
    {
        size_t chunk = len - offset;
        if (chunk > maxChunk)
            chunk = maxChunk;

        pTxCharacteristic->setValue((uint8_t *)(data + offset), chunk);
        pTxCharacteristic->notify();
        offset += chunk;

        if (offset < len)
        {
            // Brief yield between chunks to prevent BLE ring buffer congestion
            delay(2);
        }
    }
}

// sendEXGPacket() — builds JSON for the full 128-sample EXG buffer and sends.
void sendEXGPacket()
{
    StaticJsonDocument<1600> doc;
    doc["v"] = 1;
    doc["sensor"] = static_cast<uint8_t>(SensorId::EXG);
    doc["seq"] = exgSequence++;
    doc["ts"] = millis(); // ESP32 uptime ms
    doc["rate"] = EXG_SAMPLE_RATE_HZ;

    JsonArray samples = doc.createNestedArray("samples");
    for (uint16_t i = 0; i < EXG_BUFFER_SIZE; i++)
        samples.add(exgBuffer[i]);

    if (deviceConnected)
        sendJson(doc);

    Serial.printf("[EXG]  Packet seq=%lu | BLE=%s\n",
                  (unsigned long)(exgSequence - 1),
                  deviceConnected ? "sent" : "no client");
}

// sendADXLPacket() — transmits latest ADXL345 reading at 25 Hz.
void sendADXLPacket()
{
    if (!adxlAvailable)
        return;

    uint32_t now = millis();
    if ((now - adxlLastTxMs) < ADXL_TX_INTERVAL_MS)
        return;
    adxlLastTxMs = now;

    StaticJsonDocument<256> doc;
    doc["v"] = 1;
    doc["sensor"] = static_cast<uint8_t>(SensorId::ADXL345);
    doc["seq"] = adxlSequence++;
    doc["ts"] = now;

    JsonObject data = doc.createNestedObject("data");
    data["x"] = roundf(adxlX * 100.0f) / 100.0f;
    data["y"] = roundf(adxlY * 100.0f) / 100.0f;
    data["z"] = roundf(adxlZ * 100.0f) / 100.0f;

    if (deviceConnected)
        sendJson(doc);
}

// sendDHTPacket() — transmits DHT11 temperature and humidity.
void sendDHTPacket(float temperature, float humidity)
{
    StaticJsonDocument<256> doc;
    doc["v"] = 1;
    doc["sensor"] = static_cast<uint8_t>(SensorId::DHT11);
    doc["seq"] = dhtSequence++;
    doc["ts"] = millis();

    JsonObject data = doc.createNestedObject("data");
    data["temperature"] = roundf(temperature * 10.0f) / 10.0f;
    data["humidity"] = roundf(humidity * 10.0f) / 10.0f;

    if (deviceConnected)
        sendJson(doc);
}

// sendMQ135Packet() — transmits averaged raw MQ135 ADC value at 1 Hz.
void sendMQ135Packet()
{
    uint32_t now = millis();
    if ((now - mq135LastTxMs) < MQ135_TX_INTERVAL_MS)
        return;
    mq135LastTxMs = now;

    StaticJsonDocument<192> doc;
    doc["v"] = 1;
    doc["sensor"] = static_cast<uint8_t>(SensorId::MQ135);
    doc["seq"] = mq135Sequence++;
    doc["ts"] = now;

    JsonObject data = doc.createNestedObject("data");
    data["raw"] = mq135AvgRaw;

    if (deviceConnected)
        sendJson(doc);
}

// sendSoilPacket() — transmits averaged raw soil moisture ADC value at 0.5 Hz.
void sendSoilPacket()
{
    uint32_t now = millis();
    if ((now - soilLastTxMs) < SOIL_TX_INTERVAL_MS)
        return;
    soilLastTxMs = now;

    StaticJsonDocument<192> doc;
    doc["v"] = 1;
    doc["sensor"] = static_cast<uint8_t>(SensorId::SOIL_MOISTURE);
    doc["seq"] = soilSequence++;
    doc["ts"] = now;

    JsonObject data = doc.createNestedObject("data");
    data["raw"] = soilAvgRaw;

    if (deviceConnected)
        sendJson(doc);
}

// =============================================================================
// 11. SETUP
// =============================================================================
void setup()
{
    Serial.begin(115200);
    delay(200);

    Serial.println("========================================");
    Serial.println("   ESP32 Sensor Hub (BLE Edition)");
    Serial.println("========================================");
    Serial.println("[NOTE] 'ts' field = ESP32 uptime in ms (NOT Unix wall-clock time)");

    // ── Global ADC resolution (classic ESP32 = 12-bit, range 0-4095) ──────
    analogReadResolution(12);

    // ── BLE Setup ──────────────────────────────────────────────────────────
    setupBLE();

    // ── Sensor initialization ──────────────────────────────────────────────
    setupADXL345(); // I2C + ADXL345
    setupDHT();
    setupMQ135();
    setupSoilMoisture();
    setupEXG(); // Starts the micros() reference for 500 Hz timing

    Serial.println("[INIT] Initialization complete. Entering acquisition loop.");
    Serial.println("========================================");
}

// =============================================================================
// 12. LOOP — non-blocking multi-rate scheduler
// =============================================================================
void loop()
{
    // ── EXG (highest priority — micros()-based 500 Hz) ────────────────────
    if (readEXG())
    {
        sendEXGPacket(); // transmits full 128-sample buffer (~3.9 Hz)
    }

    // ── ADXL345 (100 Hz acquisition / 25 Hz BLE transmission) ─────────────
    readADXL345();    // ~100 Hz
    sendADXLPacket(); // ~25 Hz

    // ── MQ135 (10 Hz acquisition / 1 Hz BLE transmission) ─────────────────
    readMQ135();       // 10 Hz
    sendMQ135Packet(); // 1 Hz

    // ── Soil Moisture (10 Hz acquisition / 0.5 Hz BLE transmission) ───────
    readSoilMoisture(); // 10 Hz
    sendSoilPacket();   // 0.5 Hz

    // ── DHT11 (0.5 Hz acquisition + transmission) ─────────────────────────
    {
        float temperature = 0.0f;
        float humidity = 0.0f;
        if (readDHT(temperature, humidity))
            sendDHTPacket(temperature, humidity);
    }

    // ── BLE Auto-reconnection Handler ─────────────────────────────────────
    if (!deviceConnected && oldDeviceConnected)
    {
        delay(500); // Allow BLE stack to reset
        pServer->startAdvertising();
        Serial.println("[BLE] Client disconnected. Restarted advertising.");
        oldDeviceConnected = deviceConnected;
    }
    if (deviceConnected && !oldDeviceConnected)
    {
        oldDeviceConnected = deviceConnected;
    }

    // Zero delay() in this loop — all rate control is millis()/micros()-based.
}
// =============================================================================
// END OF FILE — ESP32_Sensor_Hub.ino
// =============================================================================

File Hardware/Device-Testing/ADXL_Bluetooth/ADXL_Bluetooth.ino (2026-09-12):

// =============================================================================
// ADXL_Bluetooth.ino
//
// PURPOSE:
//   Tests the ADXL345 3-axis accelerometer over I2C and streams live
//   acceleration data to a connected Bluetooth Low Energy (BLE) client
//   using the EXACT JSON protocol (v1, Sensor ID 2) expected by the
//   Sanjeevni mobile app and identical to ESP32_Sensor_Hub.ino.
//
//   Use this sketch to:
//     1. Confirm the ADXL345 is correctly wired to I2C (SDA=21, SCL=22).
//     2. Verify that the Adafruit ADXL345 library initialises the sensor.
//     3. Observe X / Y / Z acceleration values in real time on the USB
//        Serial Monitor and via the Sanjeevni mobile app over BLE.
//     4. Validate sensor readings and BLE transmission before full integration.
//
// SENSOR:
//   ADXL345 — 3-axis digital accelerometer (Analog Devices)
//   Interface  : I2C (default address 0x53; 0x1D if SDO pulled HIGH)
//   Range      : ±2G (configured here; options: ±2G, ±4G, ±8G, ±16G)
//   Output     : Acceleration in m/s² via Adafruit unified sensor API
//   Library    : Adafruit_ADXL345_U (requires Adafruit_Sensor)
//
// BOARD:
//   Classic ESP32 (ESP32-WROOM / DevKit V1), ESP32-S3, ESP32-C3 — Arduino framework
//
// WIRING:
//   ADXL345 VCC  →  3.3 V
//   ADXL345 GND  →  GND
//   ADXL345 SDA  →  GPIO 21
//   ADXL345 SCL  →  GPIO 22
//   ADXL345 SDO  →  GND  (sets I2C address to 0x53)
//   ADXL345 CS   →  3.3 V (selects I2C mode)
//
// BLE DEVICE NAME:
//   "ESP32_SENSOR_HUB_BLE" (recognized immediately by Sanjeevni mobile app)
//
// GATT PROFILE (Nordic UART Service - NUS):
//   Service UUID : 6E400001-B5A3-F393-E0A9-E50E24DCCA9E
//   TX Char UUID : 6E400003-B5A3-F393-E0A9-E50E24DCCA9E (Notify — ESP32 -> Client)
//   RX Char UUID : 6E400002-B5A3-F393-E0A9-E50E24DCCA9E (Write  — Client -> ESP32)
//
// PROTOCOL SPECIFICATION (Protocol v1 JSON, newline-delimited):
//   {"v":1,"sensor":2,"seq":<seq>,"ts":<uptime_ms>,"data":{"x":<x>,"y":<y>,"z":<z>}}\n
//
//   Example packet (as seen in sample_data.txt):
//     {"v":1,"sensor":2,"seq":4518,"ts":181483,"data":{"x":1.65,"y":-3.61,"z":-11.02}}
//
// SAMPLING & TRANSMISSION:
//   Acquisition rate: ~100 Hz (every 10 ms)
//   BLE transmission rate: 25 Hz (every 40 ms, matching ESP32_Sensor_Hub.ino)
//
// USB SERIAL:
//   Baud rate: 115200 baud
// =============================================================================

#include <Arduino.h>
#include <Wire.h>               // I2C driver — ESP32 Arduino core
#include <Adafruit_Sensor.h>    // Adafruit unified sensor abstraction
#include <Adafruit_ADXL345_U.h> // ADXL345 driver
#include <BLEDevice.h>
#include <BLEServer.h>
#include <BLEUtils.h>
#include <BLE2902.h>

// ============================================================
// PIN CONFIGURATION
// ============================================================
#define SDA_PIN 21
#define SCL_PIN 22

// ============================================================
// TIMING CONSTANTS (matching ESP32_Sensor_Hub.ino)
// ============================================================
static const uint32_t ADXL_ACQ_INTERVAL_MS = 10; // 100 Hz acquisition
static const uint32_t ADXL_TX_INTERVAL_MS  = 40; // 25 Hz BLE transmission

// ============================================================
// BLE CONFIGURATION & NORDIC UART UUIDs
// ============================================================
#define DEVICE_NAME "ESP32_SENSOR_HUB_BLE"
#define SERVICE_UUID           "6E400001-B5A3-F393-E0A9-E50E24DCCA9E"
#define CHARACTERISTIC_UUID_RX "6E400002-B5A3-F393-E0A9-E50E24DCCA9E"
#define CHARACTERISTIC_UUID_TX "6E400003-B5A3-F393-E0A9-E50E24DCCA9E"

// ============================================================
// GLOBAL OBJECTS & STATE
// ============================================================
Adafruit_ADXL345_Unified adxl = Adafruit_ADXL345_Unified(12345);

BLEServer *pServer = nullptr;
BLECharacteristic *pTxCharacteristic = nullptr;
bool deviceConnected = false;
bool oldDeviceConnected = false;

// Sequence tracking and state
uint32_t adxlSequence = 0;
uint32_t adxlLastAcqMs = 0;
uint32_t adxlLastTxMs = 0;
float adxlX = 0.0f, adxlY = 0.0f, adxlZ = 0.0f;

// Server callbacks to detect client connection and disconnection
class MyServerCallbacks : public BLEServerCallbacks
{
    void onConnect(BLEServer *pServer) override
    {
        deviceConnected = true;
        Serial.println("[BLE] Mobile client connected!");
    }

    void onDisconnect(BLEServer *pServer) override
    {
        deviceConnected = false;
        Serial.println("[BLE] Mobile client disconnected!");
    }
};

// ============================================================
// SETUP ADXL345
// ============================================================
bool setupADXL345()
{
    Wire.begin(SDA_PIN, SCL_PIN);

    if (!adxl.begin())
    {
        Serial.println("[ADXL345] ERROR: Sensor not detected! Check SDA/SCL wiring and pull-ups.");
        return false;
    }

    adxl.setRange(ADXL345_RANGE_2_G);
    Serial.println("[ADXL345] Initialized successfully (Range: ±2G, SDA=21, SCL=22)");
    return true;
}

// ============================================================
// READ ADXL345 (100 Hz acquisition)
// ============================================================
bool readADXL345()
{
    uint32_t now = millis();
    if ((now - adxlLastAcqMs) < ADXL_ACQ_INTERVAL_MS)
        return false;
    adxlLastAcqMs = now;

    sensors_event_t event;
    adxl.getEvent(&event);

    adxlX = event.acceleration.x;
    adxlY = event.acceleration.y;
    adxlZ = event.acceleration.z;
    return true;
}

// ============================================================
// SETUP BLE (Nordic UART Service)
// ============================================================
void setupBLE()
{
    BLEDevice::init(DEVICE_NAME);
    BLEDevice::setMTU(517);

    pServer = BLEDevice::createServer();
    pServer->setCallbacks(new MyServerCallbacks());

    BLEService *pService = pServer->createService(SERVICE_UUID);

    pTxCharacteristic = pService->createCharacteristic(
        CHARACTERISTIC_UUID_TX,
        BLECharacteristic::PROPERTY_NOTIFY
    );
    pTxCharacteristic->addDescriptor(new BLE2902());

    BLECharacteristic *pRxCharacteristic = pService->createCharacteristic(
        CHARACTERISTIC_UUID_RX,
        BLECharacteristic::PROPERTY_WRITE
    );

    pService->start();

    BLEAdvertising *pAdvertising = BLEDevice::getAdvertising();
    pAdvertising->addServiceUUID(SERVICE_UUID);
    pAdvertising->setScanResponse(true);
    pAdvertising->setMinPreferred(0x06);
    pAdvertising->setMinPreferred(0x12);
    BLEDevice::startAdvertising();

    Serial.printf("[BLE] GATT Server advertising as '%s'\n", DEVICE_NAME);
}
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

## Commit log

2026-09-11 initial pcb commit
    [Sanjeevni_PCB.kicad_pcb, Sanjeevni_PCB.kicad_sch]
2026-09-11 simplified pcb design md file
2026-09-11 reverted pcb design guide
2026-09-11 added programming pad functionality and battery powered design
2026-09-11 updated pcb design, using exg module instead of creating from scratch.
2026-09-11 update pcb schema
    [Sanjeevni_PCB.kicad_pcb, Sanjeevni_PCB.kicad_sch]
2026-09-11 final PCB design KiCad
    [Sanjeevni_PCB.kicad_pcb, Sanjeevni_PCB.kicad_sch]
2026-09-11 PCB rendered images
2026-09-11 pcb schema and design pdf
2026-09-12 feat(db): implement Schema v4 multi-user data isolation and CRUD operations
    - Add user_id column with composite indexing to readings and alerts tables
    - Migrate user_profile to user_id primary key and rolling_baseline to composite PK
    - Add full sensor statistics, history, and user-scoped pruning CRUD functions
    - Add Test 11 to databaseSchema.test.ts verifying multi-user data isolation
2026-09-12 feat(ui): add light and dark mode theme system with persistent preferences
    - Implement themeStore with light, dark, and system modes persisted in SecureStore
    - Adapt UniversalNavBar curved background and SOS button to dark mode
    - Style Profile, Alerts, and History screens with reactive theme palette tokens
    - Add dynamic stroke colors to ModernGraphs and MultiMetricVitalsChart
2026-09-12 feat(dashboard): add ESP32 status card, offline data freeze, and remove mock data
    - Add ESP32StatusCard with BLE connect/disconnect controls and live telemetry counter
    - Freeze live data updates when disconnected and fallback to SQLite historical averages
    - Eradicate hardcoded dummy data from mockAlertsData and mockDashboardData
    - Add header theme toggle and responsive health overview cards in Dashboard
2026-09-12 feat(portal): add localhost web portal, USB serial firmware, 500Hz ECG visualizer, and disaster resilience center (SIH 26181)
2026-09-12 fix(ble): resolve Bluetooth crash with throttled state, safe GATT order, SVG NaN guards, and remove redundant files
2026-09-12 feat(dashboard): add 500Hz real-time ECG oscilloscope, live AI reasoning box, empty chart states, 2s secondary sensor interval, and natural purpose-driven themes
2026-09-12 feat(hardware): unify device-testing BLE sketches to protocol v1, add standalone tests, relocate PCB guide, and document sample telemetry and power specs
2026-09-12 fix(ble): eliminate auto-simulation on connect, add Web Bluetooth support, and ensure dashboard updates strictly when ESP32_SENSOR_HUB_BLE is connected
